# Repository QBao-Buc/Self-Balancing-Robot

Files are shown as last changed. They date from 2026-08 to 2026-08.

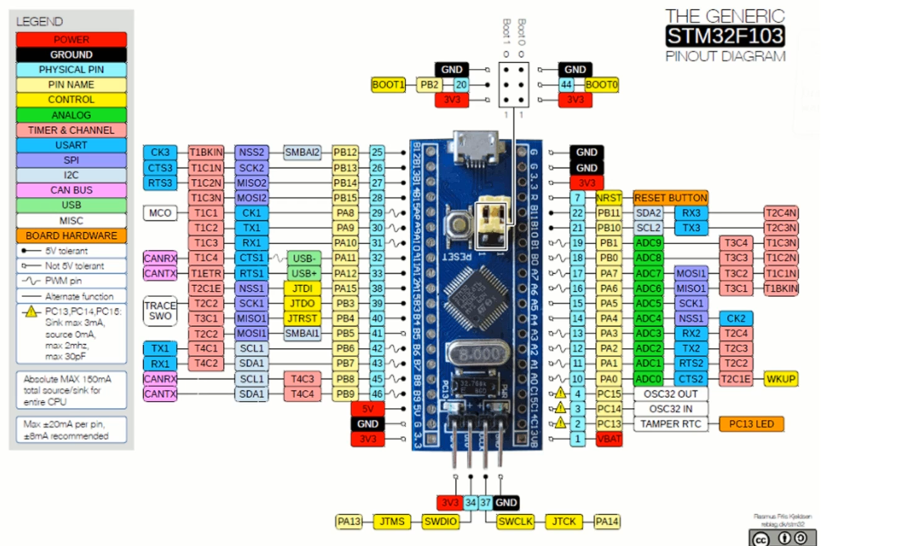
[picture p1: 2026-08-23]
docs/pinout/STM32.png

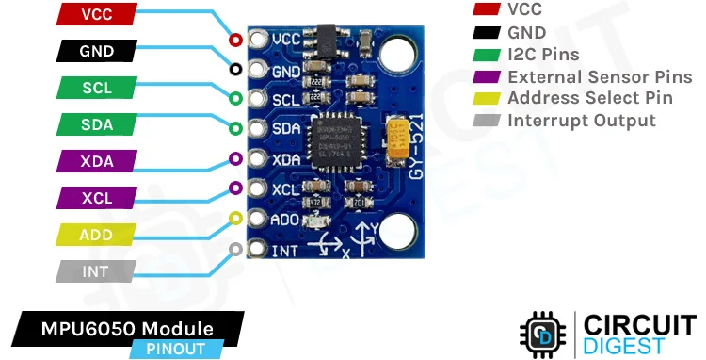
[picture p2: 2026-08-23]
docs/pinout/MPU6050-Module-Pinout.webp

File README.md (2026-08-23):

# Self-Balancing Robot (Dự án Nhúng Full-Stack)

Một dự án robot độc lập được thiết kế Full-Stack hoàn chỉnh: từ mạch cứng PCB tùy chỉnh, firmware nhúng C/C++, đến các thuật toán điều khiển PID trên vi điều khiển STM32.

---

## 📌 Tổng quan dự án

Dự án này tập trung vào việc thiết kế và chế tạo một robot 2 bánh tự cân bằng hoàn toàn từ con số 0. Hệ thống tích hợp toàn diện giữa thiết kế phần cứng, dung hợp cảm biến (sensor fusion), lý thuyết điều khiển rời rạc và lập trình hệ thống nhúng.

* **Vi điều khiển chính:** STM32F103C8T6 (Blue Pill)
* **Cảm biến:** MPU6050 (Góc nghiêng / Gia tốc 6-axis)
* **Mạch công suất:** TB6612FNG + Động cơ Encoder DC
* **Nguồn cấp:** Pin LiPo 3S (11.1V - 12.6V) qua mạch Hạ áp LM2596/Buck

---

## 🛠️ Kiến trúc Hệ thống & Đặc tính Kỹ thuật

* **Vi điều khiển:** Dòng STM32F103.
* **Phần cứng & PCB:** Thiết kế mạch nguyên lý & PCB 2 lớp tùy chỉnh, tích hợp khối cảm biến IMU MPU6050 và mạch điều khiển động cơ.
* **Firmware nhúng:** Lập trình C/C++ sử dụng thư viện STM32 HAL/Register, Ngắt bộ định thời (Timer Interrupts), và các ngoại vi I2C/PWM.
* **Chiến lược điều khiển:**
  * Dung hợp cảm biến thông qua Bộ lọc bù (Complementary Filter) / Bộ lọc Kalman để ước lượng góc nghiêng chính xác.
  * Thuật toán **PID 2 vòng kép (Cascade PID)** để cân bằng góc nghiêng, kiểm soát vận tốc và vị trí.
* **Cơ khí:** Thân vỏ khung xe in 3D tùy chỉnh được thiết kế trên SolidWorks.

---

## 📂 Cấu trúc Repository

```plaintext
Self-Balancing-Robot/
├── .gitignore
├── LICENSE
├── README.md
├── CHANGELOG.md
├── docs/                     # Tài liệu tham khảo, Datasheet & Handbook
│   ├── datasheets/           # Tập hợp Datasheet linh kiện (STM32, MPU6050, TB6612...)
│   ├── pinout/               # Sơ đồ gán chân & Pinout chi tiết
│   └── handbook/             # Nhật ký/Ghi chép quá trình phát triển & Debug
├── firmware/                 # Mã nguồn lập trình STM32 (CubeMX + Keil C)
│   ├── Core/
│   ├── Drivers/
│   ├── MDK-ARM/              # Project Keil C (.uvprojx)
│   ├── MyLib/                # Thư viện tự viết (robot_debug.c/h)
│   └── STM32F103_BalanceRobot.ioc
├── hardware/                 # Sơ đồ nguyên lý & PCB
│   ├── schematic/            # Bản vẽ nguyên lý (.PDF)
│   ├── wiring/               # Sơ đồ đấu nối dây (.PNG)
│   ├── pcb/                  # Layout PCB (.PDF)
│   └── BOM.md                # Danh mục linh kiện chi tiết
└── mechanical/               # Thiết kế cơ khí & Thân vỏ
    ├── cad/
    │   ├── circuit_parts/    # Mô hình 3D linh kiện điện tử
    │   │   ├── battery/      # Khối 3D Pin LiPo
    │   │   ├── buck/         # Khối 3D mạch hạ áp Buck
    │   │   ├── dong_co/      # Khối 3D động cơ Encoder
    │   │   ├── hc05/         # Khối 3D module Bluetooth HC-05
    │   │   ├── mpu/          # Khối 3D cảm biến MPU6050
    │   │   └── pcb/          # Khối 3D bo mạch PCB
    │   └── stl_print/        # File .STL phục vụ in 3D
    ├── drawings/             # Bản vẽ 3D tổng thể (.STEP) & bản vẽ 2D (.PDF)
    └── README.md             # Hướng dẫn in 3D & chế tạo
  
```
## 🚀 Tính năng chính của Robot
Giao tiếp & Debug: Gửi/nhận dữ liệu không dây qua Bluetooth HC-05, theo dõi thông số thực thời trên máy tính qua phần mềm Tera Term 5 (MyLib/robot_debug).

Cơ chế bảo vệ an toàn:
Dead Angle Protection: Tự động ngắt động cơ khi xe nghiêng quá góc cho phép (tránh trôi xe hoặc quá tải khi đổ).
Bảo vệ điện áp/Dòng: (Đang hoàn thiện)

Tính năng phụ trợ:
Điều khiển còi kèn (Buzzer) phát tín hiệu cảnh báo.
Hiệu ứng đèn LED trạng thái (nháy LED báo lỗi / chế độ hoạt động).
(Lưu ý: Các tính năng trên đang tiếp tục được tối ưu và hoàn thiện trong code).

## 📋 Danh mục chi tiết cần chuẩn bị (BOM)
Để xem danh sách đầy đủ tất cả linh kiện điện tử, động cơ, cảm biến và vật tư cơ khí cần chuẩn bị cho dự án:
👉 Mời bạn truy cập vào file: hardware/BOM.md

---

## 🛠️ Sơ đồ nguyên lý & Bảng chân đấu nối (Pinout)
### 1. Sơ đồ nguyên lý (Schematic)
(Phần này để trống - Cập nhật sơ đồ nguyên lý hoặc đường dẫn bản vẽ sau)

### 2. Sơ đồ đấu nối phần cứng
Chi tiết đấu nối giữa STM32, TB6612, Động cơ Encoder và Nguồn:

## 📖 Hướng dẫn lắp ráp & Vận hành
### 1. Phần cơ khí & Thân vỏ
In tất cả các file .STL nằm tại mechanical/cad/stl_print/ và xem bản vẽ lắp ráp tổng thể .STEP tại mechanical/drawings/.

### 2. Phần cứng & Nguồn
(Phần này để trống - Cập nhật hướng dẫn đấu nối chi tiết)

### 3. Nạp code Firmware
Mở project tại firmware/MDK-ARM/STM32F103_BalanceRobot.uvprojx bằng Keil uVision 5.

Build và nạp code xuống STM32 bằng mạch nạp ST-Link V2.

## 📄 Giấy phép (License)
Dự án được phân phối dưới giấy phép MIT License.

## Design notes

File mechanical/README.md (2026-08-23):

# 🛠️ Thiết kế Cơ khí & Thân vỏ (Mechanical)

Thư mục này chứa toàn bộ tài liệu thiết kế cơ khí, mô hình 3D linh kiện, file in 3D và bản vẽ lắp ráp cho robot tự cân bằng.

---

## 📂 Cấu trúc thư mục & Giải thích chức năng

```plaintext
mechanical/
├── README.md               # Hướng dẫn chi tiết phần cơ khí (File này)
├── cad/                    # Thư mục thiết kế mô hình 3D (CAD Models)
│   ├── circuit_parts/      # Mô hình 3D các linh kiện điện tử & bo mạch
│   │   ├── battery/        # Mô hình 3D Pin LiPo
│   │   ├── buck/           # Mô hình 3D mạch hạ áp Buck
│   │   ├── dong_co/        # Mô hình 3D động cơ DC Encoder
│   │   ├── hc05/           # Mô hình 3D Module Bluetooth HC-05
│   │   ├── mpu/            # Mô hình 3D Cảm biến MPU6050
│   │   └── pcb/            # Mô hình 3D Bo mạch PCB
│   └── stl_print/          # Các file định dạng .STL dùng để in 3D
└── drawings/               # Bản vẽ tổng thể & Kỹ thuật
    ├── *.STEP              # File lắp ráp 3D tổng thể (Assembly STEP)
    └── *.PDF               # Bản vẽ 2D / Sơ đồ chi tiết kích thước
```

## 📖 Hướng dẫn sử dụng từng phần

### 1. Thư mục cad/circuit_parts/ (Mô hình linh kiện điện tử)
Chức năng: Chứa mô hình 3D (STEP/SolidWorks) của từng linh kiện điện tử thực tế.

Cách dùng: Sử dụng khi bạn muốn tự thiết kế lại khung xe/PCB bằng các phần mềm CAD (SolidWorks, Fusion 360, Inventor). Hãy Import các file này vào phần mềm thiết kế để lấy chính xác kích thước và vị trí bắt ốc.

### 2. Thư mục cad/stl_print/ (File in 3D)
Chức năng: Chứa các file định dạng .STL của thân vỏ, gá động cơ, khay pin đã được tối ưu cho máy in 3D.

Cách dùng:

Mở phần mềm Cắt lát (Slicer) như Cura, PrusaSlicer, hoặc Bambu Studio.

Import tất cả file .STL trong thư mục này.

Tiến hành Cắt lát (Slice) và xuất file .gcode ra thẻ nhớ để đưa vào máy in 3D.

Khuyến nghị thông số in: Infill 20% - 30% (dạng Gyroid/Grid), độ dày thành (Wall thickness) >= 1.2mm, vật liệu in PLA hoặc PETG.

### 3. Thư mục drawings/ (Bản vẽ tổng thể)
Chức năng: Chứa bản vẽ phối cảnh 3D tổng thể (.STEP) và bản vẽ kỹ thuật 2D (.PDF).

Cách dùng:

File .STEP: Mở bằng phần mềm CAD để xem tổng thể robot sau khi lắp ráp đầy đủ khung, động cơ, mạch và pin.

File .PDF: Xem trực tiếp để nắm kích thước tổng thể robot và vị trí lắp ghép chuẩn.

## 👉 Để quay lại hướng dẫn chung của toàn bộ dự án, truy cập Trang README chính.

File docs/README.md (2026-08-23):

# 📚 Tài liệu tham khảo & Nhật ký phát triển (Docs)

Thư mục này chứa toàn bộ các tài liệu kỹ thuật, datasheet linh kiện, bản đồ gán chân (Pinout Mapping) và tài liệu nhật ký ghi chép quá trình nghiên cứu, chế tạo robot tự cân bằng.

---

## 📂 Cấu trúc lưu trữ

```plaintext
docs/
├── README.md               # Trang hướng dẫn & Tổng quan thư mục tài liệu
├── datasheets/             # Tập hợp Datasheet PDF của các linh kiện
├── pinout/                 # Sơ đồ kết nối chân & Bảng tra cứu Pinout chi tiết
└── handbook/               # Nhật ký ghi chép, tài liệu tính toán & Debug
```

---

## 📖 Danh mục tài liệu chi tiết

### 1. 📄 Datasheets (`docs/datasheets/`)
Tài liệu kỹ thuật gốc từ nhà sản xuất phục vụ tra cứu thông số điện áp, dòng điện, thanh ghi (registers) và các chuẩn giao tiếp:
* **STM32F103C8T6:** Datasheet vi điều khiển ARM Cortex-M3 & Reference Manual (`RM0008`).
* **MPU6050:** Product Specification & Register Map (Bộ lọc dung hợp cảm biến IMU 6-axis).
* **TB6612FNG:** Datasheet mạch cầu H điều khiển động cơ DC.
* **HC-05:** Tài liệu cấu hình Bluetooth Module & Tập lệnh AT Command.
* **LM2596 / Buck Converter:** Datasheet mạch nguồn hạ áp.

---

### 2. 📌 Pinout & Sơ đồ đấu nối (`docs/pinout/`)
* **Sơ đồ gán chân tổng thể:** Bảng tra cứu chân kết nối giữa STM32F103C8T6 với các ngoại vi (I2C MPU6050, Timer Encoder, PWM TB6612, UART Bluetooth).
* **Sơ đồ mạch nguyên lý & Wiring:** Bản vẽ kết nối dây thực tế giúp người dùng có thể lắp ráp nhanh chóng.

---

### 3. 📝 Handbook & Nhật ký dự án (`docs/handbook/`)
Tài liệu hướng dẫn chuyên sâu từ con số 0:
* **Lý thuyết & Thuật toán:** Giải thuật lọc bù (Complementary Filter), Kalman Filter và thuật toán điều khiển PID 2 vòng kép (Cascade PID).
* **Kinh nghiệm cân chỉnh (PID Tuning):** Quy trình thực tế để chỉnh các thông số $K_p, K_i, K_d$.
* **Xử lý sự cố (Troubleshooting):** Tổng hợp các vấn đề thường gặp (nhiễu IMU, trôi góc 0, sụt áp do động cơ, nhiễu nguồn...) và cách khắc phục.

---

👉 *Để xem hướng dẫn nạp code và chạy dự án, vui lòng quay lại [Trang README chính](../README.md).*

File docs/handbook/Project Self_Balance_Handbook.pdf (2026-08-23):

Nguyễn Quốc Bảo
Sinh viên Công nghệ kĩ thuật, ngành cơ điện tử, khóa K24

Điều khiển động cơ bằng PWM
Nhiệm vụ số 1: _Điều khiển được động cơ bằng PWM

_Sử dụng được encoder + Điều khiển tốc độ động cơ + số chân cắm vào phải tương ứng với mạch
Nhiệm vụ nhỏ:
Xác định toàn bộ chân động cơ ở trong ảnh -> viết lại dưới dạng mạch breadboard ở fritzing

#MINI TASK: Điều khiển được tốc độ của động cơ DC thông qua TB6612 bằng PWM + sử dụng các cổng trùng với sơ đồ minh họa , (tôi điều khiển động cơ với tốc độ từ 0% -> 100% sau đó 100%->0%) _motor trái

Màu dây / Tên cổng | Chức năng | Nối vào
⚪White (1) | Cực 1 Motor | BO1 (TB6612)
Blue (2) | Encoder VCC | 3.3V (STM32)
Green (3) | Encoder Channel B | B10 STM32 (TIMx_CH2 hoặc GPIO)
Yellow (4) | Encoder Channel A | B11 STM32 (TIMx_CH1 hoặc GPIO)
⚫Black (5) | Encoder GND | GND
Red (6) | Cực 2 Motor | BO2 (TB6612)

#NOTE: khi đấu mạch, phải đảm bảo

_cực âm của Pin, GND của STM32, GND của TB6612 phải được nối đến GND chung, nếu không nó sẽ không chạy.

_Chân STBY (standby) ở TB6612: Công tắc bật/tắt driver -> HIGH -> Driver hoạt động -> động cơ chạy
_Chân BO1và BO2: dung để đấu vào 2 cực của động cơ để điều khiển

_motor phải
Màu dây / Tên cổng | Chức năng | Nối vào
⚪White (1) | Cực 1 Motor | AO1 (TB6612)
Blue (2) | Encoder VCC | 3.3V (STM32)
Green (3) | Encoder Channel B | B08 STM32 (TIMx_CH2 hoặc GPIO)
Yellow (4) | Encoder Channel A | B09 STM32 (TIMx_CH1 hoặc GPIO)
⚫Black (5) | Encoder GND | GND
Red | (6) | Cực 2 Motor | AO2 (TB6612) _TB6612:
Cổng TB6612 | Nối đến | Cổng TB6612 | Nối đến
VM | 12V | PWMA | A0
VCC | 3.3V | AI1 | A2
GND | GND | AI2 | A3
A01 | WHITE (động cơ R) | STBY | A4 (HIGH/LOW)
A02 | RED( động cơ R) | BI1 | A5
B02 | WHITE (động cơ L) | BI2 | A6
B01 | RED (động cơ L) | PWMB | A1
GND | GND (STM32) | GND

Cấu hình CubeMX:

### 1. RCC

HSE = Crystal/Ceramic Resonator

### 2. SYS

Debug = Serial Wire

### 3. Clock Configuration

Mục | Giá trị
HSE | 8 MHz
PLL Source HSE
PLL Mul | ×9
SYSCLK | 72 MHz
AHB | /1
APB1 | /2
APB2 | /1
ADC | /6

### 4. TIM2 (PWM)

Enable:
TIM2
Chọn
Channel | Mode
CH1 | PWM Generation CH1
CH2 | PWM Generation CH2
Parameter Settings
Thông số | Giá trị
Prescaler | 0

Thông số | Giá trị
Counter Period (ARR) | 3599
Counter Mode | Up
Clock Division | DIV1
Auto Reload Preload | Enable
Lúc này

### 72 MHz

↓
ARR = 3599
↓
PWM = 20 kHz
Đây là tần số rất phổ biến cho điều khiển động cơ DC vì nằm ngoài dải nghe của tai người. 5. GPIO
Pin | Mode | Label
PA2 | GPIO_Output | AIN1
PA3 | GPIO_Output | AIN2
PA4 | GPIO_Output | STBY
PA5 | GPIO_Output | BIN1
PA6 | GPIO_Output | BIN2

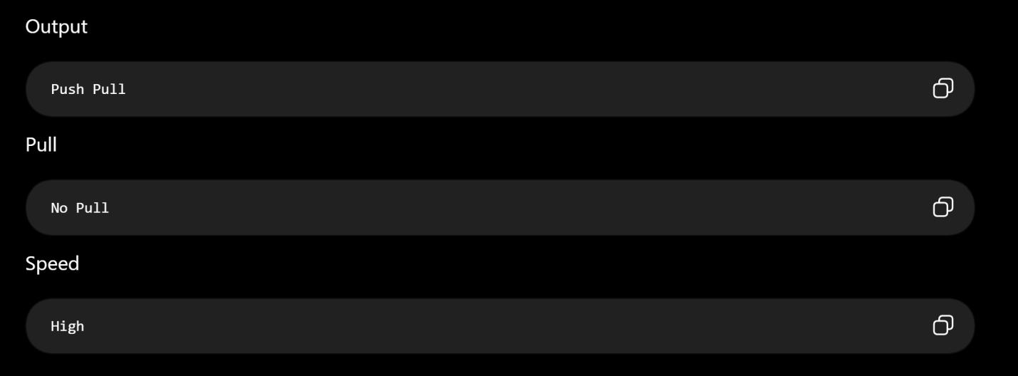
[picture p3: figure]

### 6. PWM Pins

CubeMX sẽ tự gán
Pin | Chức năng
PA0 TIM2_CH1
PA1 TIM2_CH2

### 7. Encoder

Tạm thời
Pin | Mode
PB10 GPIO_Input
PB11 GPIO_Input

### 8. NVIC

Hiện tại Không cần bật Interrupt

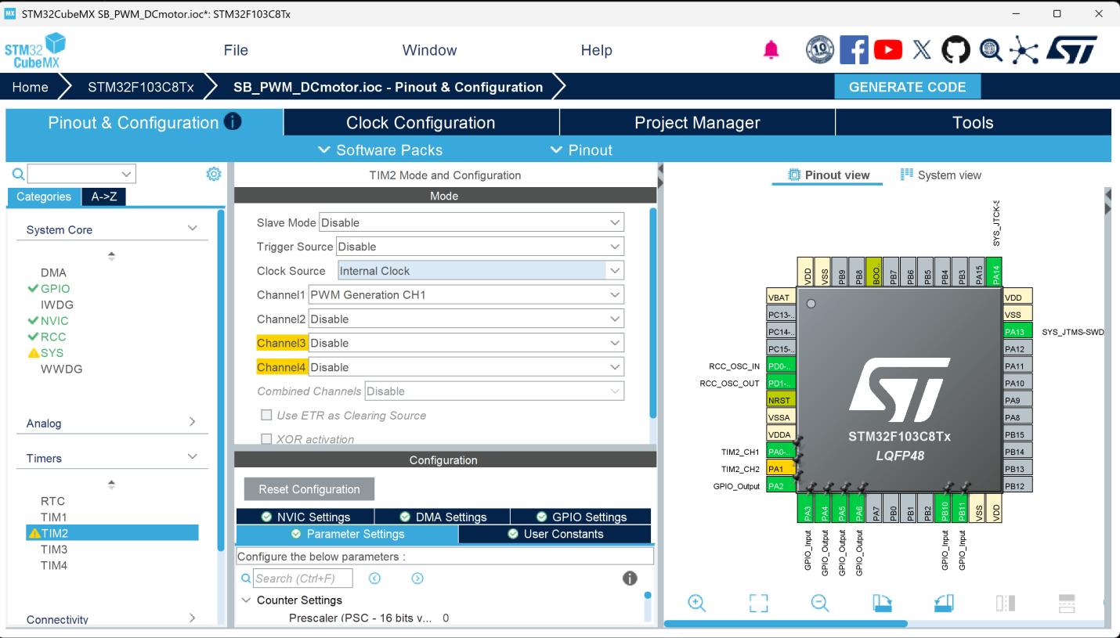
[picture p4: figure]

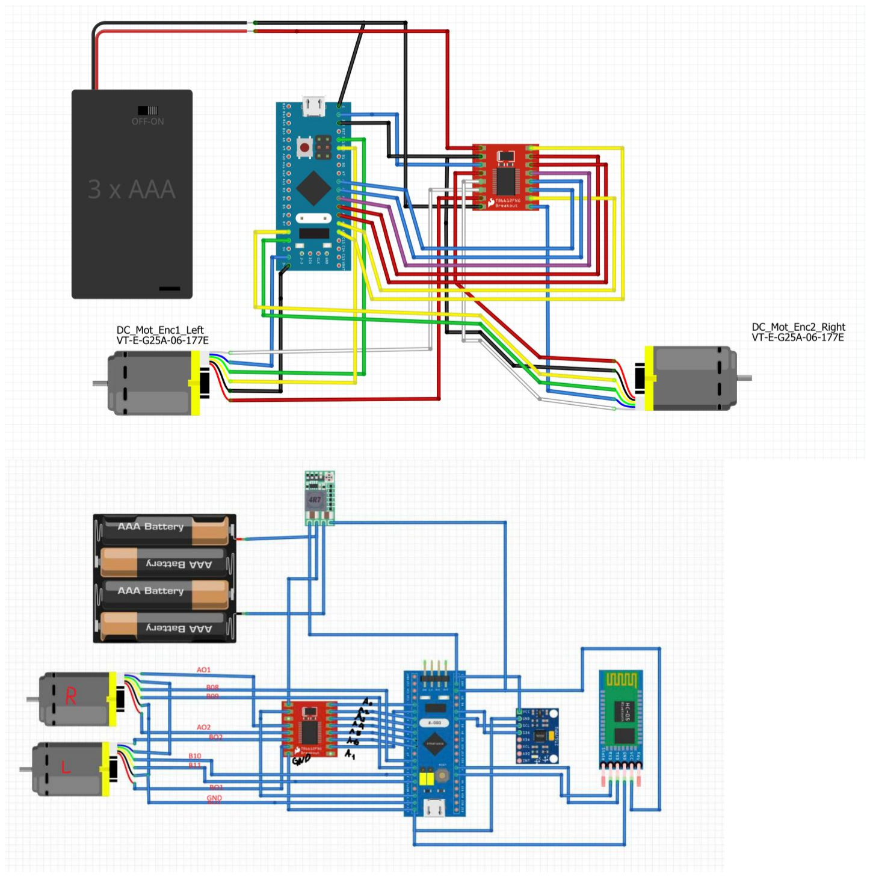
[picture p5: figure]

#note: cái hình này chưa hẳn đã đúng, nên kiểm tra lại tính chính xác, bởi vì gần đây đã có sự thay đổi về mặt phần cứng

### 1. STM32 ↔ TB6612

STM32 Chế độ trong CubeMX TB6612 Chức năng
PA0 | TIM2_CH1 (PWM) | PWMA | Điều khiển tốc độ động cơ phải
PA1 | TIM2_CH2 (PWM) | PWMB | Điều khiển tốc độ động cơ trái
PA2 | GPIO Output | AIN1 | Chiều quay động cơ phải
PA3 | GPIO Output | AIN2 | Chiều quay động cơ phải
PA4 | GPIO Output | STBY | Enable TB6612
PA5 | GPIO Output | BIN1 | Chiều quay động cơ trái
PA6 | GPIO Output | BIN2 | Chiều quay động cơ trái
3.3V | Power | VCC | Nguồn logic TB6612
GND | GND | GND | Mass chung

### 2. TB6612 ↔ Động cơ

Động cơ phải
TB6612 | Động cơ
AO1 | White
AO2 | Red
Động cơ trái
TB6612 | Động cơ
BO1 | Red
BO2 | White

### 3. Encoder động cơ trái

Dây encoder | STM32 | Chức năng
Black | 3.3V | VCC
Blue | GND | GND
Yellow | PB11 | Channel A
Green | PB10 | Channel B

### 4. Nguồn

Nguồn | TB6612
+12V (hoặc nguồn động cơ của bạn) | VM
3.3V STM32 | VCC
GND nguồn | GND
GND STM32 | GND
Lưu ý: GND của STM32, TB6612 và nguồn động cơ phải nối chung. 5. Các chân đang được chương trình sử dụng

STM32 Chức năng
PA0 | PWM Motor Right
PA1 | PWM Motor Left
PA2 | AIN1
PA3 | AIN2

STM32 Chức năng
PA4 | STBY
PA5 | BIN1
PA6 | BIN2
PB10 | Encoder B (chưa sử dụng trong code)
PB11 | Encoder A (chưa sử dụng trong code)

### 6. Trạng thái các chân trong chương trình

Khi quay thuận
Chân | Mức
STBY | HIGH
AIN1 | HIGH
AIN2 | LOW
BIN1 | HIGH
BIN2 | LOW
PWMA | PWM 0 → 100%
PWMB | PWM 0 → 100%

Khi quay ngược
Chân | Mức
STBY | HIGH

Chân | Mức
AIN1 | LOW
AIN2 | HIGH
BIN1 | LOW
BIN2 | HIGH
PWMA | PWM 0 → 100%
PWMB | PWM 0 → 100%

#MiniTask 2: Việc của bạn là sử dụng được Encoder của động cơ, hiển thị các thông số vị trí của bánh 1 và bánh 2, yêu cầu đấu nối giống với những gì đã thiết lập

<đã xong> (file

#MiniTask3: Việc của bạn là thử điều khiển PID nó, thử tác động một lực quay nhất định rồi yêu cầu nó quay trở về vị trí cũ. <đã xong>

/* USER CODE BEGIN Header */
/**
******************************************************************************
* @file | : main.c
* @brief | : Main program body
****************************************************************************** * @attention
*

* Copyright (c) 2026 STMicroelectronics. * All rights reserved. *

* This software is licensed under terms that can be found in the LICENSE file * in the root directory of this software component. * If no LICENSE file comes with this software, it is provided AS-IS. *

****************************************************************************** */
/* USER CODE END Header */
/* Includes ------------------------------------------------------------------*/ #include "main.h"

/* Private includes ----------------------------------------------------------*/ /* USER CODE BEGIN Includes */

/* USER CODE END Includes */

/* Private typedef -----------------------------------------------------------*/ /* USER CODE BEGIN PTD */

/* USER CODE END PTD */

/* Private define ------------------------------------------------------------*/

/* USER CODE BEGIN PD */

/* USER CODE END PD */

/* Private macro -------------------------------------------------------------*/ /* USER CODE BEGIN PM */

/* USER CODE END PM */

/* Private variables ---------------------------------------------------------*/ TIM_HandleTypeDef htim2;
TIM_HandleTypeDef htim3;

/* USER CODE BEGIN PV */
int pwm = 0;
volatile int32_t encoder_position = 0; volatile int16_t cnt = 0;
int16_t encoder_last = 0;
int32_t target_position = 0;

/* PID */
float Kp = 0.1f;

float Ki = 0.01f;
float Kd = 0.5f;

float integral = 0.0f;
float previous_error = 0.0f; float last_error = 0;
float derivative = 0.0f;

float error = 0;

/* USER CODE END PV */

/* Private function prototypes -----------------------------------------------*/ void SystemClock_Config(void);
static void MX_GPIO_Init(void);
static void MX_TIM2_Init(void);
static void MX_TIM3_Init(void);
/* USER CODE BEGIN PFP */
void HAL_TIM_MspPostInit(TIM_HandleTypeDef *htim); void Motor_SetPWM(int pwm);

void Encoder_Update(void);

/* USER CODE END PFP */

/* Private user code ---------------------------------------------------------*/ /* USER CODE BEGIN 0 */

/* USER CODE END 0 */

/**
* @brief The application entry point. * @retval int

*/
int main(void)
{

/* USER CODE BEGIN 1 */

/* USER CODE END 1 */

/* MCU Configuration--------------------------------------------------------*/

/* Reset of all peripherals, Initializes the Flash interface and the Systick. */ HAL_Init();

/* USER CODE BEGIN Init */

/* USER CODE END Init */

/* Configure the system clock */ SystemClock_Config();

/* USER CODE BEGIN SysInit */

/* USER CODE END SysInit */

/* Initialize all configured peripherals */ MX_GPIO_Init();
MX_TIM2_Init();
MX_TIM3_Init();
/* USER CODE BEGIN 2 */
// Khoi dong cc knh xung PWM trn TIMER 2 HAL_TIM_PWM_Start(&htim2, TIM_CHANNEL_1); HAL_TIM_PWM_Start(&htim2, TIM_CHANNEL_2);
// Bat chn STBY de kch hoat IC driver TB6612 (PA4) HAL_GPIO_WritePin(GPIOA, GPIO_PIN_4, GPIO_PIN_SET);

HAL_TIM_Encoder_Start(&htim3, TIM_CHANNEL_ALL); encoder_last = (int16_t)__HAL_TIM_GET_COUNTER(&htim3); Encoder_Update();
target_position = encoder_position;
Encoder_Update();

/* USER CODE END 2 */

/* Infinite loop */
/* USER CODE BEGIN WHILE */ volatile int32_t temp = 0;

while (1)
{
/* USER CODE END WHILE */

/* USER CODE BEGIN 3 */
Encoder_Update();

cnt = (int16_t)__HAL_TIM_GET_COUNTER(&htim3); error = target_position - encoder_position;

// Khâu Tích phân (I)
integral += error;

// integral Windup
if(integral > 5000) integral = 5000; if(integral < -5000) integral = -5000;

// Khâu Vi phân (D)
derivative = error - last_error;

// Tính toán đầu ra PID
pwm = (int)(Kp * error + Ki * integral + Kd * derivative);

// CẬP NHẬT SAI SỐ CŨ CHO CHU KỲ SAU (BẮT BUỘC) last_error = error;

// Vùng chết (Deadband)
if(error > -3 && error < 3) {
pwm = 0;
}

// Giới hạn điện áp PWM đầu ra chống quá tải hệ thống if(pwm > 1200) pwm = 1200;

if(pwm < -1200) pwm = -1200;

Motor_SetPWM(pwm);

HAL_Delay(5);
}
/* USER CODE END 3 */
}

/**
* @brief System Clock Configuration * @retval None
*/
void SystemClock_Config(void)
{
RCC_OscInitTypeDef RCC_OscInitStruct = {0};
RCC_ClkInitTypeDef RCC_ClkInitStruct = {0};

/** Initializes the RCC Oscillators according to the specified parameters * in the RCC_OscInitTypeDef structure. */

RCC_OscInitStruct.OscillatorType = RCC_OSCILLATORTYPE_HSE; RCC_OscInitStruct.HSEState = RCC_HSE_ON; RCC_OscInitStruct.HSEPredivValue = RCC_HSE_PREDIV_DIV1;

RCC_OscInitStruct.HSIState = RCC_HSI_ON; RCC_OscInitStruct.PLL.PLLState = RCC_PLL_ON; RCC_OscInitStruct.PLL.PLLSource = RCC_PLLSOURCE_HSE; RCC_OscInitStruct.PLL.PLLMUL = RCC_PLL_MUL9;
if (HAL_RCC_OscConfig(&RCC_OscInitStruct) != HAL_OK) {
Error_Handler();
}

/** Initializes the CPU, AHB and APB buses clocks
*/
RCC_ClkInitStruct.ClockType = RCC_CLOCKTYPE_HCLK|RCC_CLOCKTYPE_SYSCLK |RCC_CLOCKTYPE_PCLK1|RCC_CLOCKTYPE_PCLK2; RCC_ClkInitStruct.SYSCLKSource = RCC_SYSCLKSOURCE_PLLCLK; RCC_ClkInitStruct.AHBCLKDivider = RCC_SYSCLK_DIV1; RCC_ClkInitStruct.APB1CLKDivider = RCC_HCLK_DIV2; RCC_ClkInitStruct.APB2CLKDivider = RCC_HCLK_DIV1;

if (HAL_RCC_ClockConfig(&RCC_ClkInitStruct, FLASH_LATENCY_2) != HAL_OK) {
Error_Handler();
}
}

/**
* @brief TIM2 Initialization Function * @param None
* @retval None
*/
static void MX_TIM2_Init(void)
{

/* USER CODE BEGIN TIM2_Init 0 */

/* USER CODE END TIM2_Init 0 */

TIM_ClockConfigTypeDef sClockSourceConfig = {0}; TIM_MasterConfigTypeDef sMasterConfig = {0}; TIM_OC_InitTypeDef sConfigOC = {0};

/* USER CODE BEGIN TIM2_Init 1 */

/* USER CODE END TIM2_Init 1 */
htim2.Instance = TIM2;
htim2.Init.Prescaler = 0;
htim2.Init.CounterMode = TIM_COUNTERMODE_UP; htim2.Init.Period = 3599;
htim2.Init.ClockDivision = TIM_CLOCKDIVISION_DIV1;

htim2.Init.AutoReloadPreload = TIM_AUTORELOAD_PRELOAD_ENABLE; if (HAL_TIM_Base_Init(&htim2) != HAL_OK)
{
Error_Handler();
}
sClockSourceConfig.ClockSource = TIM_CLOCKSOURCE_INTERNAL;
if (HAL_TIM_ConfigClockSource(&htim2, &sClockSourceConfig) != HAL_OK) {
Error_Handler();
}
if (HAL_TIM_PWM_Init(&htim2) != HAL_OK) {
Error_Handler();
}
sMasterConfig.MasterOutputTrigger = TIM_TRGO_RESET; sMasterConfig.MasterSlaveMode = TIM_MASTERSLAVEMODE_DISABLE; if (HAL_TIMEx_MasterConfigSynchronization(&htim2, &sMasterConfig) != HAL_OK)

{
Error_Handler();
}
sConfigOC.OCMode = TIM_OCMODE_PWM1; sConfigOC.Pulse = 0;
sConfigOC.OCPolarity = TIM_OCPOLARITY_HIGH; sConfigOC.OCFastMode = TIM_OCFAST_DISABLE;

if (HAL_TIM_PWM_ConfigChannel(&htim2, &sConfigOC, TIM_CHANNEL_1) != HAL_OK)

{
Error_Handler();
}
if (HAL_TIM_PWM_ConfigChannel(&htim2, &sConfigOC, TIM_CHANNEL_2) != HAL_OK)

{
Error_Handler();
}
/* USER CODE BEGIN TIM2_Init 2 */

/* USER CODE END TIM2_Init 2 */ HAL_TIM_MspPostInit(&htim2);

}

/**
* @brief TIM3 Initialization Function * @param None
* @retval None
*/
static void MX_TIM3_Init(void) {

/* USER CODE BEGIN TIM3_Init 0 */

/* USER CODE END TIM3_Init 0 */

TIM_Encoder_InitTypeDef sConfig = {0}; TIM_MasterConfigTypeDef sMasterConfig = {0};

/* USER CODE BEGIN TIM3_Init 1 */

/* USER CODE END TIM3_Init 1 */
htim3.Instance = TIM3;
htim3.Init.Prescaler = 0;
htim3.Init.CounterMode = TIM_COUNTERMODE_UP; htim3.Init.Period = 65535;
htim3.Init.ClockDivision = TIM_CLOCKDIVISION_DIV1; htim3.Init.AutoReloadPreload = TIM_AUTORELOAD_PRELOAD_DISABLE; sConfig.EncoderMode = TIM_ENCODERMODE_TI12; sConfig.IC1Polarity = TIM_ICPOLARITY_RISING;
sConfig.IC1Selection = TIM_ICSELECTION_DIRECTTI; sConfig.IC1Prescaler = TIM_ICPSC_DIV1; sConfig.IC1Filter = 10;
sConfig.IC2Polarity = TIM_ICPOLARITY_RISING; sConfig.IC2Selection = TIM_ICSELECTION_DIRECTTI; sConfig.IC2Prescaler = TIM_ICPSC_DIV1;

sConfig.IC2Filter = 10;
if (HAL_TIM_Encoder_Init(&htim3, &sConfig) != HAL_OK) {
Error_Handler();
}
sMasterConfig.MasterOutputTrigger = TIM_TRGO_RESET; sMasterConfig.MasterSlaveMode = TIM_MASTERSLAVEMODE_DISABLE; if (HAL_TIMEx_MasterConfigSynchronization(&htim3, &sMasterConfig) != HAL_OK)

{
Error_Handler();
}
/* USER CODE BEGIN TIM3_Init 2 */

/* USER CODE END TIM3_Init 2 */

}

/**
* @brief GPIO Initialization Function * @param None
* @retval None
*/
static void MX_GPIO_Init(void) {

GPIO_InitTypeDef GPIO_InitStruct = {0}; /* USER CODE BEGIN MX_GPIO_Init_1 */

/* USER CODE END MX_GPIO_Init_1 */

/* GPIO Ports Clock Enable */ __HAL_RCC_GPIOD_CLK_ENABLE(); __HAL_RCC_GPIOA_CLK_ENABLE(); __HAL_RCC_GPIOB_CLK_ENABLE();

/*Configure GPIO pin Output Level */
HAL_GPIO_WritePin(GPIOA, GPIO_PIN_2|GPIO_PIN_3|GPIO_PIN_4|GPIO_PIN_5 |GPIO_PIN_6, GPIO_PIN_RESET);

/*Configure GPIO pins : PA2 PA3 PA4 PA5
PA6 */
GPIO_InitStruct.Pin = GPIO_PIN_2|GPIO_PIN_3|GPIO_PIN_4|GPIO_PIN_5 |GPIO_PIN_6;
GPIO_InitStruct.Mode = GPIO_MODE_OUTPUT_PP; GPIO_InitStruct.Pull = GPIO_NOPULL;
GPIO_InitStruct.Speed = GPIO_SPEED_FREQ_LOW; HAL_GPIO_Init(GPIOA, &GPIO_InitStruct);

/* USER CODE BEGIN MX_GPIO_Init_2 */

/* USER CODE END MX_GPIO_Init_2 */ }

/* USER CODE BEGIN 4 */

// Hm x? l ng?t ngoi d? d?m xung Encoder t? chn PB10 v PB11

void Motor_SetPWM(int pwm)
{
// Giới hạn giá trị PWM đầu ra theo cấu hình Timer (Period = 3599) if(pwm > 3599) pwm = 3599;
if(pwm < -3599) pwm = -3599;

if(pwm <= 0) // Quay thuận khi pwm dương hoặc bằng 0 {
// QUAY THUAN: IN1 = 1, IN2 = 0 HAL_GPIO_WritePin(GPIOA, GPIO_PIN_5, GPIO_PIN_SET); HAL_GPIO_WritePin(GPIOA, GPIO_PIN_6, GPIO_PIN_RESET);

// Nạp giá trị PWM dương trực tiếp __HAL_TIM_SET_COMPARE(&htim2, TIM_CHANNEL_2, pwm); }
else // Quay nghịch khi pwm < 0

{
// QUAY NGHICH: IN1 = 0, IN2 = 1 HAL_GPIO_WritePin(GPIOA, GPIO_PIN_5, GPIO_PIN_RESET); HAL_GPIO_WritePin(GPIOA, GPIO_PIN_6, GPIO_PIN_SET);

// ĐỔI DẤU SỐ ÂM THÀNH SỐ DƯƠNG (Thêm dấu trừ) __HAL_TIM_SET_COMPARE(&htim2, TIM_CHANNEL_2, -pwm);

}
}

void Encoder_Update(void)
{
int16_t now;
int16_t delta;

now = (int16_t)__HAL_TIM_GET_COUNTER(&htim3);

delta = now - encoder_last;

encoder_last = now;

encoder_position += delta; }
/* USER CODE END 4 */

/**
* @brief This function is executed in case of error occurrence. * @retval None

*/
void Error_Handler(void)
{
/* USER CODE BEGIN Error_Handler_Debug */
/* User can add his own implementation to report the HAL error return state */ __disable_irq();
while (1)
{
}
/* USER CODE END Error_Handler_Debug */ }
#ifdef USE_FULL_ASSERT

/**
* @brief Reports the name of the source file and the source line number * where the assert_param error has occurred. * @param file: pointer to the source file name

* @param line: assert_param error line source number
* @retval None
*/
void assert_failed(uint8_t *file, uint32_t line)

{
/* USER CODE BEGIN 6 */
/* User can add his own implementation to report the file name and line number, ex: printf("Wrong parameters value: file %s on line %d\r\n", file, line) */

/* USER CODE END 6 */
}
#endif /* USE_FULL_ASSERT */

#NOTE: đổi chân encoder motor trái thành PB4 PB5

#MiniTask4: Tìm ra bài toán động học và làm sao cho nó đứng được. #MiniTask5: Tunning bằng module blue tooth, học cách sử dụng và Tunning

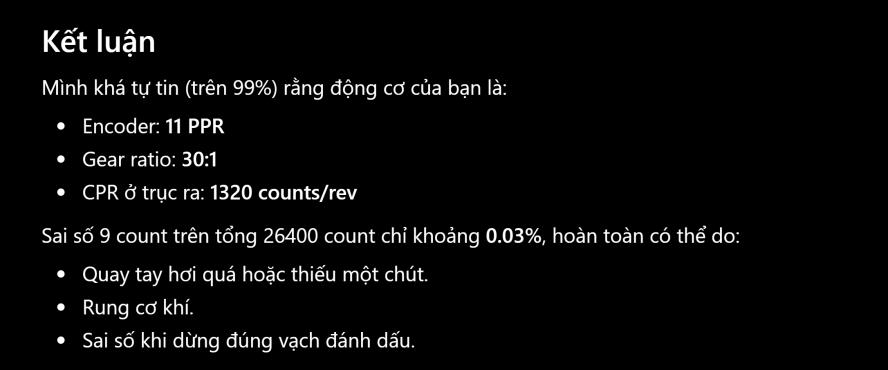
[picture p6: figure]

#MINI TASK 3.2: encoder speed: sử dụng encoder để tính tốc độ RPM để phục vụ cho bài toán động học giữa MPU và Động cơ. Module 1: Encoder Speed

Mục tiêu
Mỗi 10 ms tính được:

Position (count)
↓

Delta Count

↓

RPM

↓

Filtered RPM

Bước 1. Cấu hình CubeMX
TIM3
Giữ nguyên như hiện tại
Mode:
Encoder Mode

Prescaler = 0

Period = 65535

Encoder Mode = TI12

IC1 Filter = 10

IC2 Filter = 10

TIM4
Tạo timer định kỳ. Ví dụ Clock:

### 72 MHz

Ta muốn

### 10 ms => 100 Hz

Chọn
PSC = 7199

ARR = 99
Vì

### 72 MHz

↓

72000000/(7199+1) =

10000 Hz

↓

10000/(99+1) =

100 Hz =

### 10 ms

Sau đó
Enable Update Interrupt

Bước 2. Tạo biến
Ngay đầu main.c
typedef struct
{
int32_t position;
int32_t last_position;
int32_t delta;

float rpm;
float rpm_filter;

}Encoder_t;

Encoder_t encoder;

Bước 3. Thêm

#define ENCODER_CPR | 1320.0f

#define SAMPLE_TIME | 0.01f

#define RPM_FACTOR (60.0f/(ENCODER_CPR*SAMPLE_TIME)) Compiler sẽ tính sẵn

RPM_FACTOR =

4.54545

Bước 4. Khởi động

HAL_TIM_Encoder_Start(&htim3,TIM_CHANNEL_ALL);

HAL_TIM_Base_Start_IT(&htim4);

Bước 5. Viết hàm

void Encoder_Update(void)
{
encoder.position = (int16_t)__HAL_TIM_GET_COUNTER(&htim3);

encoder.delta =
encoder.position - encoder.last_position;

encoder.last_position =
encoder.position;

encoder.rpm =
encoder.delta * RPM_FACTOR;

encoder.rpm_filter =
0.8f*encoder.rpm_filter+
0.2f*encoder.rpm;
}
#Side Quest: Hiện tại việc Debug PID rất phiền, nên chúng ta chuyển sang sử dụng UART để debug -> học sử dụng HC-05 bluetooth trước

HC-05
STATE
RXD | PA9
TXD | PA10
GND | GND
VCC | 5V
EN
PA9 PA10

Bước 1: Kết nối phần cứng
Nếu dùng USART1 của Blue Pill: HC-05 STM32F103
VCC 5V
GND GND
TXD PA10 (USART1_RX)
RXD PA9 (USART1_TX)
Lưu ý
TX luôn nối RX
RX luôn nối TX
STM32 PA9 ----------> RX HC05

STM32 PA10 <---------- TX HC05

Bước 2: CubeMX

Mở CubeMX. USART1

Chọn
Mode

Asynchronous

Baudrate
9600

Word Length

### 8 Bits

Parity
None

Stop Bits
1

Hardware Flow Control
None

Mode
TX and RX

DMA
Disable
Interrupt
Disable
Hiện tại chúng ta chỉ truyền dữ liệu nên chưa cần ngắt. Bước 3: Clock

Để USART ổn định:
SYSCLK = 72 MHz
Nếu trước đó Motor và Encoder hoạt động bình thường thì giữ nguyên. Bước 4: Kiểm tra HC-05

Cấp nguồn. Quan sát LED. Trường hợp 1

LED nhấp nhanh
- • • • • • => Chưa kết nối Bluetooth. Đây là trạng thái bình thường. Trường hợp 2

LED nhấp chậm
- • • => Đã kết nối điện thoại.

Bước 5: Ghép nối điện thoại Bật Bluetooth. Tìm

HC-05
Nếu hỏi mật khẩu
1234
hoặc
0000
Theo datasheet, mã PIN mặc định có thể là 0000 trong chế độ hoạt động và 1234 sau khi khôi phục mặc định bằng AT+ORGL, tùy firmware của module. Bước 6

Cài ứng dụng
Serial Bluetooth Terminal
(Đây là ứng dụng mình thường dùng để debug UART qua HC-05.)

Bước 7
Sau khi Pair thành công
Kết nối tới HC-05. Nếu LED chuyển sang nhấp chậm

=> Thành công. Bước 8

Chưa cần viết code.

Mình muốn kiểm tra phần cứng trước. Bạn hãy gửi cho mình:

1. Ảnh module HC-05 của bạn (hai mặt nếu được) để xem đây là bản ZS-040, FC-114 hay loại khác. 2. File .ioc hiện tại của dự án STM32 (hoặc ảnh cấu hình CubeMX phần

USART1). Sau khi mình kiểm tra cấu hình, chúng ta sẽ sang Bài 2, chỉ với khoảng 10 dòng

code để STM32 gửi:
Hello STM32
Nếu điện thoại nhận được dòng này, tức là toàn bộ đường truyền STM32 → UART → HC-05 → Bluetooth đã hoạt động chính xác. Sau đó chúng ta mới bắt đầu xây

dựng thư viện Bluetooth.

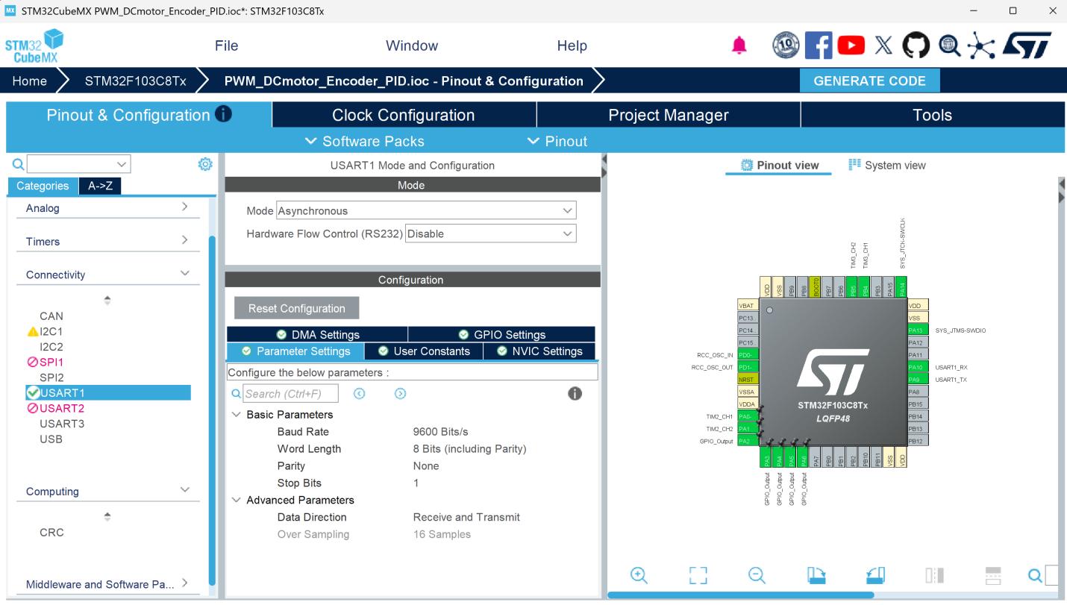
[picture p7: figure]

Kiểm tra phần cứng
Hãy nối đúng như sau:
HC-05 STM32

HC-05 STM32
VCC 5V
GND GND
TXD PA10 (RX1)
RXD PA9 (TX1)
⚠ Lưu ý quan trọng: • TX của HC-05 → RX của STM32
- RX của HC-05 ← TX của STM32

void HAL_UART_RxCpltCallback(UART_HandleTypeDef *huart) {
if(huart->Instance == USART1)
{
HAL_UART_Transmit(&huart1,&rxChar,1,100); if(rxChar == '\r' || rxChar == '\n') {
rxBuffer[rxIndex] = '\0';

rxIndex = 0;

cmdReady = 1;
}
else
{
if(rxIndex < sizeof(rxBuffer)-1) {
rxBuffer[rxIndex++] = rxChar; }
}

HAL_UART_Receive_IT(&huart1, &rxChar, 1);
}
}
#MINI Task viết giao thức để giao tiếp với STM32 bằng UART Bluetooth

Mục tiêu là khi nhập lệnh thì STM32 phải phản hồi lại, từ đó phục vụ cho việc tunning không dây
_làm cho nó phản hồi được

Phân tích nguyên nhân (Root Cause Analysis)
1. Xung đột ngắt & HAL Deadlock giữa TIM4 và UART (Nguyên nhân chính) • Hiện trạng: TIM4 ngắt mỗi 10ms (100Hz). Trong callback

HAL_TIM_PeriodElapsedCallback, bạn gọi Control_Loop(), và trong đó có dòng:
C
Motor_SetPWM(3599); // Hoặc các tính toán liên tục
- Lỗi trong Callback Echo:
C
void HAL_UART_RxCpltCallback(UART_HandleTypeDef *huart) {
if(huart->Instance == USART1)
{
// DÙNG HAL_MAX_DELAY TRONG INTERRUPT CONTEXT! HAL_UART_Transmit(&huart1, (uint8_t*) &rxChar, 1, HAL_MAX_DELAY); HAL_UART_Receive_IT(&huart1, (uint8_t*) &rxChar, 1);
}
} • Hậu quả:
1. HAL_UART_Transmit với HAL_MAX_DELAY là hàm blocking (chờ lặp). Gọi hàm blocking ngay bên trong ISR (Interrupt Service Routine) của

UART là điều cấm kỵ. Nếu đường truyền bị nhiễu hoặc HC-05 chưa sẵn sàng nhận, MCU sẽ bị khóa cứng (Deadlock) ngay trong ISR. 2. Mức ưu tiên ngắt (Priority): Nếu TIM4 ngắt đè lên UART khi đang

truyền dữ liệu, UART State của HAL sẽ bị đơ (HAL_BUSY), khiến các lệnh HAL_UART_Receive_IT tiếp theo bị từ chối trả về HAL_ERROR.

### 2. Thiếu ngắt NVIC cho USART1

- Khi cấu hình bằng STM32CubeMX, nếu chỉ chọn USART1 Asynchronous mà chưa tích chọn "USART1 global interrupt" trong mục NVIC Settings, lệnh HAL_UART_Receive_IT() sẽ chỉ chạy đúng 1 lần rồi im lặng mãi mãi vì phần cứng không bao giờ nhảy vào ISR. Từng bước khắc phục & Kiểm chứng (Debug Steps)

Bước 1: Kiểm tra cấu hình NVIC trong CubeMX
Mở file .ioc trong STM32CubeIDE:
1. Vào Connectivity →USART1. 2. Sang tab NVIC Settings. 3. Tích chọn USART1 global interrupt →Enabled. 4. Generate Code lại (Ctrl + S). Bước 2: Sửa lại code Echo Interrupt an toàn (Không Blocking)

Sửa lại hàm HAL_UART_RxCpltCallback để loại bỏ HAL_MAX_DELAY. Thay vào đó, dùng hằng số Timeout ngắn (ví dụ 10ms), hoặc gửi bằng ngắt/xử lý ngoài main:

C
/* USER CODE BEGIN 4 */

void HAL_UART_RxCpltCallback(UART_HandleTypeDef *huart) {
if(huart->Instance == USART1)
{
// 1. Phản hồi ngay ký tự vừa nhận với Timeout an toàn (10ms) thay vì HAL_MAX_DELAY
HAL_UART_Transmit(&huart1, (uint8_t*)&rxChar, 1, 10);

// 2. Kích hoạt lại ngắt nhận 1 byte tiếp theo ngay lập tức HAL_UART_Receive_IT(&huart1, (uint8_t*)&rxChar, 1);
}
}

/* USER CODE END 4 */
Bước 3: Xử lý Tràn bộ đệm & Tự khôi phục lỗi UART (Overrun Error Handling) Một lỗi rất phổ biến khiến UART ngưng nhận dữ liệu trên STM32 HAL là Overrun Error (ORE). Khi ký tự đến quá nhanh mà MCU chưa kịp đọc, HAL sẽ khóa ngắt UART. Thêm hàm callback xử lý lỗi này vào cuối file main.c để tự khôi phục ngắt nếu có

sự cố nhiễu/tràn phím:
C
void HAL_UART_ErrorCallback(UART_HandleTypeDef *huart)
{
if(huart->Instance == USART1)
{
// Xóa cờ lỗi ORE/NE/FE nếu có __HAL_UART_CLEAR_OREFLAG(huart); __HAL_UART_CLEAR_NEFLAG(huart); __HAL_UART_CLEAR_FEFLAG(huart);

// Kích hoạt lại ngắt nhận HAL_UART_Receive_IT(&huart1, (uint8_t*)&rxChar, 1); }

}
Kịch bản Test Echo trên điện thoại
1. Nạp firmware đã cập nhật ở trên vào Blue Pill. 2. Mở ứng dụng Serial Bluetooth trên điện thoại (ví dụ: Serial Bluetooth

Terminal trên Android). 3. Kết nối với HC-05. 4. Gõ từng ký tự (ví dụ: H, E, L, L, O). 5. Kỳ vọng: Mỗi khi bạn bấm 1 phím trên điện thoại, ký tự đó sẽ lập tức xuất

hiện ngược lại trên màn hình app. Nếu Echo hoạt động thành công, ta đã chứng minh 100%: HC-05✓ ⟶
USART1 Hardware✓ ⟶ NVIC Interrupt✓ ⟶ HAL Callback✓

Bạn hãy thực hiện kiểm tra Bước 1 & Bước 2 trên phần cứng. Cho mình biết kết quả Echo (có nhận được ký tự phản hồi từng chữ cái hay chưa) để chúng ta bước sang Tầng Parser & Xây dựng CLI Ring Buffer nhé!

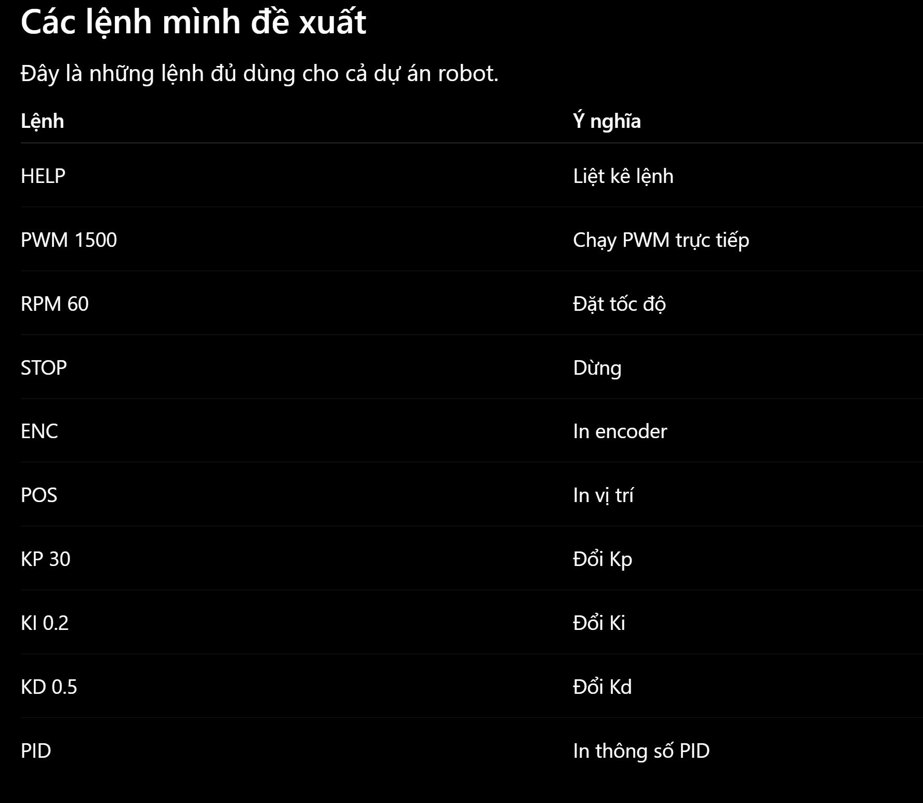
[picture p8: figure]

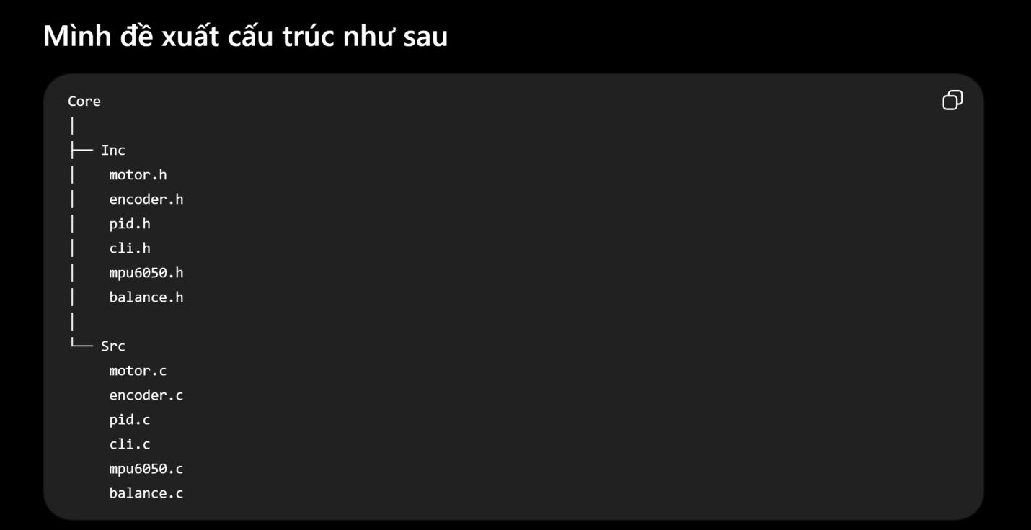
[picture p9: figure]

/* USER CODE BEGIN Header */
/**
******************************************************************************
* @file | : main.c
* @brief | : Main program body
****************************************************************************** * @attention
*
* Copyright (c) 2026 STMicroelectronics. * All rights reserved. *

* This software is licensed under terms that can be found in the LICENSE file * in the root directory of this software component. * If no LICENSE file comes with this software, it is provided AS-IS. *

****************************************************************************** */
/* USER CODE END Header */
/* Includes ------------------------------------------------------------------*/ #include "main.h"

/* Private includes ----------------------------------------------------------*/ /* USER CODE BEGIN Includes */
#include <string.h>

#include <stdio.h>

#include <stdlib.h>

/* USER CODE END Includes */
/* Private typedef -----------------------------------------------------------*/ /* USER CODE BEGIN PTD */
typedef struct
{
float Kp;
float Ki;
float Kd;
float Ts;
float setpoint;
float feedback;
float output;
float error;
float last_error;
float integral;
float derivative;
// Các thành phần kết quả nhân P, I, D riêng biệt float P_term;
float I_term;
float D_term;
float outMax;
float outMin;
float iMax;
float iMin;
} PID_t;
typedef enum {

MODE_MANUAL_PWM = 0, MODE_PID_SPEED = 1
} ControlMode_t;
typedef enum {
PRINT_OFF = 0, PRINT_MONITOR, // In dạng chữ chi tiết có cả Kp, Ki, Kd PRINT_PLOT // In dạng CSV để vẽ đồ thị
} PrintMode_t;
/* USER CODE END PTD */
/* Private define ------------------------------------------------------------*/ /* USER CODE BEGIN PD */
#define ENCODER_CPR 1320.0f

#define SAMPLE_TIME 0.01f

#define RPM_FACTOR (60.0f / (ENCODER_CPR * SAMPLE_TIME))

/* USER CODE END PD */
/* Private macro -------------------------------------------------------------*/ /* USER CODE BEGIN PM */
/* USER CODE END PM */
/* Private variables ---------------------------------------------------------*/ TIM_HandleTypeDef htim2;
TIM_HandleTypeDef htim3;
TIM_HandleTypeDef htim4;
UART_HandleTypeDef huart1;
/* USER CODE BEGIN PV */
// Control & Mode Flags
volatile ControlMode_t control_mode = MODE_MANUAL_PWM; volatile PrintMode_t print_mode = PRINT_OFF;
volatile uint8_t print_flag = 0; // Cờ báo đến giờ in (100ms) int manual_pwm = 0;
volatile int32_t encoder_position = 0;
volatile int16_t encoder_now = 0;
volatile int16_t encoder_old = 0;

volatile int16_t encoder_delta = 0; volatile float encoder_rpm = 0.0f; float target_rpm = 0.0f;
volatile uint32_t timer_cnt = 0; // UART CLI Variables
volatile uint8_t rxChar;
char rxBuffer[32];
uint8_t rxIndex = 0;
volatile uint8_t cmdReady = 0; PID_t Speed_PID;
PID_t Angle_PID;
/* USER CODE END PV */
/* Private function prototypes -----------------------------------------------*/ void SystemClock_Config(void);
static void MX_GPIO_Init(void);
static void MX_TIM2_Init(void);
static void MX_TIM3_Init(void);
static void MX_TIM4_Init(void);
static void MX_USART1_UART_Init(void);
/* USER CODE BEGIN PFP */
void HAL_TIM_MspPostInit(TIM_HandleTypeDef *htim); void Motor_SetPWM(int pwm);
void Encoder_Update(void);
void PID_Init(PID_t *pid);
float PID_Update(PID_t *pid); void Process_Command(void);
void Process_Print(void);
/* USER CODE END PFP */
/* Private user code ---------------------------------------------------------*/ /* USER CODE BEGIN 0 */
/* USER CODE END 0 */
/**
* @brief The application entry point.

* @retval int
*/
int main(void)
{
/* USER CODE BEGIN 1 */
/* USER CODE END 1 */
/* MCU Configuration--------------------------------------------------------*/ /* Reset of all peripherals, Initializes the Flash interface and the Systick. */ HAL_Init();
/* USER CODE BEGIN Init */
/* USER CODE END Init */
/* Configure the system clock */ SystemClock_Config();
/* USER CODE BEGIN SysInit */
/* USER CODE END SysInit */
/* Initialize all configured peripherals */ MX_GPIO_Init();
MX_TIM2_Init();
MX_TIM3_Init();
MX_TIM4_Init();
MX_USART1_UART_Init();
/* USER CODE BEGIN 2 */
// Khởi động các kênh xung PWM trên TIMER 2 HAL_TIM_PWM_Start(&htim2, TIM_CHANNEL_1); HAL_TIM_PWM_Start(&htim2, TIM_CHANNEL_2);
// Bật chân STBY để kích hoạt IC driver TB6612 (PA4) HAL_GPIO_WritePin(GPIOA, GPIO_PIN_4, GPIO_PIN_SET); // Khởi động Encoder TIM3

HAL_TIM_Encoder_Start(&htim3, TIM_CHANNEL_ALL); encoder_old = (int16_t)__HAL_TIM_GET_COUNTER(&htim3); // Cấu hình PID Speed mặc định
Speed_PID.Kp = 40.0f;
Speed_PID.Ki = 0.0f;
Speed_PID.Kd = 0.0f;
Speed_PID.Ts = SAMPLE_TIME; Speed_PID.outMax = 3599.0f; Speed_PID.outMin = -3599.0f; Speed_PID.iMax = 1000.0f;
Speed_PID.iMin = -1000.0f; PID_Init(&Speed_PID);
// Bắt đầu Timer ngắt chu kỳ 10ms (100Hz) HAL_TIM_Base_Start_IT(&htim4);
// Kích hoạt ngắt nhận UART1 (1 byte) HAL_UART_Receive_IT(&huart1, (uint8_t*)&rxChar, 1); /* USER CODE END 2 */
/* Infinite loop */
/* USER CODE BEGIN WHILE */
while (1)
{
/* USER CODE END WHILE */
/* USER CODE BEGIN 3 */
// 1. Xử lý lệnh từ UART / Bluetooth if (cmdReady)
{
cmdReady = 0;
Process_Command();
}
// 2. Xuất dữ liệu Monitor / Plotter ngoài luồng ngắt (chu kỳ 100ms) Process_Print();
}
/* USER CODE END 3 */
}

/**
* @brief System Clock Configuration * @retval None
*/
void SystemClock_Config(void)
{
RCC_OscInitTypeDef RCC_OscInitStruct = {0};
RCC_ClkInitTypeDef RCC_ClkInitStruct = {0};
/** Initializes the RCC Oscillators according to the specified parameters * in the RCC_OscInitTypeDef structure. */
RCC_OscInitStruct.OscillatorType = RCC_OSCILLATORTYPE_HSE; RCC_OscInitStruct.HSEState = RCC_HSE_ON; RCC_OscInitStruct.HSEPredivValue = RCC_HSE_PREDIV_DIV1; RCC_OscInitStruct.HSIState = RCC_HSI_ON; RCC_OscInitStruct.PLL.PLLState = RCC_PLL_ON; RCC_OscInitStruct.PLL.PLLSource = RCC_PLLSOURCE_HSE; RCC_OscInitStruct.PLL.PLLMUL = RCC_PLL_MUL9;
if (HAL_RCC_OscConfig(&RCC_OscInitStruct) != HAL_OK) {
Error_Handler();
}
/** Initializes the CPU, AHB and APB buses clocks
*/
RCC_ClkInitStruct.ClockType = RCC_CLOCKTYPE_HCLK|RCC_CLOCKTYPE_SYSCLK |RCC_CLOCKTYPE_PCLK1|RCC_CLOCKTYPE_PCLK2; RCC_ClkInitStruct.SYSCLKSource = RCC_SYSCLKSOURCE_PLLCLK; RCC_ClkInitStruct.AHBCLKDivider = RCC_SYSCLK_DIV1; RCC_ClkInitStruct.APB1CLKDivider = RCC_HCLK_DIV2; RCC_ClkInitStruct.APB2CLKDivider = RCC_HCLK_DIV1;
if (HAL_RCC_ClockConfig(&RCC_ClkInitStruct, FLASH_LATENCY_2) != HAL_OK) {
Error_Handler();
}
}

/**
* @brief TIM2 Initialization Function * @param None
* @retval None
*/
static void MX_TIM2_Init(void)
{
/* USER CODE BEGIN TIM2_Init 0 */
/* USER CODE END TIM2_Init 0 */ TIM_ClockConfigTypeDef sClockSourceConfig = {0}; TIM_MasterConfigTypeDef sMasterConfig = {0}; TIM_OC_InitTypeDef sConfigOC = {0};
/* USER CODE BEGIN TIM2_Init 1 */
/* USER CODE END TIM2_Init 1 */
htim2.Instance = TIM2;
htim2.Init.Prescaler = 0;
htim2.Init.CounterMode = TIM_COUNTERMODE_UP; htim2.Init.Period = 3599;
htim2.Init.ClockDivision = TIM_CLOCKDIVISION_DIV1; htim2.Init.AutoReloadPreload = TIM_AUTORELOAD_PRELOAD_ENABLE; if (HAL_TIM_Base_Init(&htim2) != HAL_OK)
{
Error_Handler();
}
sClockSourceConfig.ClockSource = TIM_CLOCKSOURCE_INTERNAL;
if (HAL_TIM_ConfigClockSource(&htim2, &sClockSourceConfig) != HAL_OK) {
Error_Handler();
}
if (HAL_TIM_PWM_Init(&htim2) != HAL_OK) {
Error_Handler();
}
sMasterConfig.MasterOutputTrigger = TIM_TRGO_RESET; sMasterConfig.MasterSlaveMode = TIM_MASTERSLAVEMODE_DISABLE;

if (HAL_TIMEx_MasterConfigSynchronization(&htim2, &sMasterConfig) != HAL_OK) {
Error_Handler();
}
sConfigOC.OCMode = TIM_OCMODE_PWM1; sConfigOC.Pulse = 0;
sConfigOC.OCPolarity = TIM_OCPOLARITY_HIGH;
sConfigOC.OCFastMode = TIM_OCFAST_DISABLE;
if (HAL_TIM_PWM_ConfigChannel(&htim2, &sConfigOC, TIM_CHANNEL_1) != HAL_OK) {
Error_Handler();
}
if (HAL_TIM_PWM_ConfigChannel(&htim2, &sConfigOC, TIM_CHANNEL_2) != HAL_OK) {
Error_Handler();
}
/* USER CODE BEGIN TIM2_Init 2 */ /* USER CODE END TIM2_Init 2 */ HAL_TIM_MspPostInit(&htim2);
}
/**
* @brief TIM3 Initialization Function * @param None
* @retval None
*/
static void MX_TIM3_Init(void)
{
/* USER CODE BEGIN TIM3_Init 0 */
/* USER CODE END TIM3_Init 0 */ TIM_Encoder_InitTypeDef sConfig = {0}; TIM_MasterConfigTypeDef sMasterConfig = {0};

/* USER CODE BEGIN TIM3_Init 1 */ /* USER CODE END TIM3_Init 1 */
htim3.Instance = TIM3;
htim3.Init.Prescaler = 0;
htim3.Init.CounterMode = TIM_COUNTERMODE_UP; htim3.Init.Period = 65535;
htim3.Init.ClockDivision = TIM_CLOCKDIVISION_DIV1; htim3.Init.AutoReloadPreload = TIM_AUTORELOAD_PRELOAD_DISABLE; sConfig.EncoderMode = TIM_ENCODERMODE_TI12; sConfig.IC1Polarity = TIM_ICPOLARITY_RISING;
sConfig.IC1Selection = TIM_ICSELECTION_DIRECTTI; sConfig.IC1Prescaler = TIM_ICPSC_DIV1; sConfig.IC1Filter = 10;
sConfig.IC2Polarity = TIM_ICPOLARITY_RISING; sConfig.IC2Selection = TIM_ICSELECTION_DIRECTTI; sConfig.IC2Prescaler = TIM_ICPSC_DIV1; sConfig.IC2Filter = 10;
if (HAL_TIM_Encoder_Init(&htim3, &sConfig) != HAL_OK) {
Error_Handler();
}
sMasterConfig.MasterOutputTrigger = TIM_TRGO_RESET; sMasterConfig.MasterSlaveMode = TIM_MASTERSLAVEMODE_DISABLE; if (HAL_TIMEx_MasterConfigSynchronization(&htim3, &sMasterConfig) != HAL_OK) {
Error_Handler();
}
/* USER CODE BEGIN TIM3_Init 2 */ /* USER CODE END TIM3_Init 2 */ }
/**
* @brief TIM4 Initialization Function * @param None
* @retval None

*/
static void MX_TIM4_Init(void)
{
/* USER CODE BEGIN TIM4_Init 0 */
/* USER CODE END TIM4_Init 0 */ TIM_ClockConfigTypeDef sClockSourceConfig = {0}; TIM_MasterConfigTypeDef sMasterConfig = {0}; /* USER CODE BEGIN TIM4_Init 1 */
/* USER CODE END TIM4_Init 1 */
htim4.Instance = TIM4;
htim4.Init.Prescaler = 7199;
htim4.Init.CounterMode = TIM_COUNTERMODE_UP; htim4.Init.Period = 99;
htim4.Init.ClockDivision = TIM_CLOCKDIVISION_DIV1; htim4.Init.AutoReloadPreload = TIM_AUTORELOAD_PRELOAD_DISABLE; if (HAL_TIM_Base_Init(&htim4) != HAL_OK)
{
Error_Handler();
}
sClockSourceConfig.ClockSource = TIM_CLOCKSOURCE_INTERNAL;
if (HAL_TIM_ConfigClockSource(&htim4, &sClockSourceConfig) != HAL_OK) {
Error_Handler();
}
sMasterConfig.MasterOutputTrigger = TIM_TRGO_RESET; sMasterConfig.MasterSlaveMode = TIM_MASTERSLAVEMODE_DISABLE; if (HAL_TIMEx_MasterConfigSynchronization(&htim4, &sMasterConfig) != HAL_OK) {
Error_Handler();
}
/* USER CODE BEGIN TIM4_Init 2 */ /* USER CODE END TIM4_Init 2 */

}
/**
* @brief USART1 Initialization Function * @param None
* @retval None
*/
static void MX_USART1_UART_Init(void) {
/* USER CODE BEGIN USART1_Init 0 */ /* USER CODE END USART1_Init 0 */ /* USER CODE BEGIN USART1_Init 1 */ /* USER CODE END USART1_Init 1 */ huart1.Instance = USART1;
huart1.Init.BaudRate = 115200; huart1.Init.WordLength = UART_WORDLENGTH_8B; huart1.Init.StopBits = UART_STOPBITS_1; huart1.Init.Parity = UART_PARITY_NONE; huart1.Init.Mode = UART_MODE_TX_RX; huart1.Init.HwFlowCtl = UART_HWCONTROL_NONE; huart1.Init.OverSampling = UART_OVERSAMPLING_16; if (HAL_UART_Init(&huart1) != HAL_OK)
{
Error_Handler();
}
/* USER CODE BEGIN USART1_Init 2 */ /* USER CODE END USART1_Init 2 */ }
/**
* @brief GPIO Initialization Function * @param None
* @retval None
*/

static void MX_GPIO_Init(void)
{
GPIO_InitTypeDef GPIO_InitStruct = {0}; /* USER CODE BEGIN MX_GPIO_Init_1 */ /* USER CODE END MX_GPIO_Init_1 */ /* GPIO Ports Clock Enable */
__HAL_RCC_GPIOD_CLK_ENABLE(); __HAL_RCC_GPIOA_CLK_ENABLE(); __HAL_RCC_GPIOB_CLK_ENABLE();

/*Configure GPIO pin Output Level */
HAL_GPIO_WritePin(GPIOA, GPIO_PIN_2|GPIO_PIN_3|GPIO_PIN_4|GPIO_PIN_5 |GPIO_PIN_6, GPIO_PIN_RESET); /*Configure GPIO pins : PA2 PA3 PA4 PA5
PA6 */
GPIO_InitStruct.Pin = GPIO_PIN_2|GPIO_PIN_3|GPIO_PIN_4|GPIO_PIN_5 |GPIO_PIN_6;
GPIO_InitStruct.Mode = GPIO_MODE_OUTPUT_PP; GPIO_InitStruct.Pull = GPIO_NOPULL;
GPIO_InitStruct.Speed = GPIO_SPEED_FREQ_LOW; HAL_GPIO_Init(GPIOA, &GPIO_InitStruct);
/* USER CODE BEGIN MX_GPIO_Init_2 */
/* USER CODE END MX_GPIO_Init_2 */
}
/* USER CODE BEGIN 4 */
void Motor_SetPWM(int pwm)
{
if(pwm > 3599) pwm = 3599; if(pwm < -3599) pwm = -3599;
if(pwm >= 0)
{
HAL_GPIO_WritePin(GPIOA, GPIO_PIN_5, GPIO_PIN_SET);

HAL_GPIO_WritePin(GPIOA, GPIO_PIN_6, GPIO_PIN_RESET); __HAL_TIM_SET_COMPARE(&htim2, TIM_CHANNEL_2, pwm); }
else
{
HAL_GPIO_WritePin(GPIOA, GPIO_PIN_5, GPIO_PIN_RESET); HAL_GPIO_WritePin(GPIOA, GPIO_PIN_6, GPIO_PIN_SET); __HAL_TIM_SET_COMPARE(&htim2, TIM_CHANNEL_2, -pwm); }
}
void Encoder_Update(void)
{
encoder_now = (int16_t)__HAL_TIM_GET_COUNTER(&htim3); encoder_delta = encoder_now - encoder_old;
encoder_old = encoder_now;
encoder_position += encoder_delta;
encoder_rpm = (float)encoder_delta * RPM_FACTOR; }
void Control_Loop(void)
{
Encoder_Update();
if (control_mode == MODE_PID_SPEED) {
Speed_PID.feedback = encoder_rpm; Speed_PID.setpoint = target_rpm; float out = PID_Update(&Speed_PID); Motor_SetPWM((int)out);
}
else
{
Motor_SetPWM(manual_pwm);
}
}
void HAL_TIM_PeriodElapsedCallback(TIM_HandleTypeDef *htim) {

if(htim->Instance == TIM4)
{
timer_cnt++;
Control_Loop(); // Tính toán PID mỗi 10ms
// Bật cờ xuất dữ liệu UART sau mỗi 100ms (10 x 10ms) static uint8_t print_cnt = 0;
if (++print_cnt >= 10)
{
print_cnt = 0;
if (print_mode != PRINT_OFF) {
print_flag = 1;
}
}
}
}
void PID_Init(PID_t *pid)
{
pid->error = 0.0f;
pid->last_error = 0.0f;
pid->integral = 0.0f;
pid->derivative = 0.0f;
pid->P_term = 0.0f;
pid->I_term = 0.0f;
pid->D_term = 0.0f;
pid->output = 0.0f;
pid->setpoint = 0.0f;
pid->feedback = 0.0f;
}
float PID_Update(PID_t *pid)
{
pid->error = pid->setpoint - pid->feedback;
// Tích phân (Integral)
pid->integral += pid->error * pid->Ts;
if(pid->integral > pid->iMax) pid->integral = pid->iMax; if(pid->integral < pid->iMin) pid->integral = pid->iMin;

// Vi phân (Derivative)
pid->derivative = (pid->error - pid->last_error) / pid->Ts; // Tính riêng từng thành phần
pid->P_term = pid->Kp * pid->error;
pid->I_term = pid->Ki * pid->integral;
pid->D_term = pid->Kd * pid->derivative;
// Tổng ngõ ra
pid->output = pid->P_term + pid->I_term + pid->D_term; // Bão hòa ngõ ra PWM
if(pid->output > pid->outMax) pid->output = pid->outMax; if(pid->output < pid->outMin) pid->output = pid->outMin; pid->last_error = pid->error;
return pid->output;
}
/*======================================================= =============
* UART MONITOR / PLOTTER PRINT PROCESSOR (Chạy trong vòng lặp while(1)) *======================================================= ============= */
void Process_Print(void)
{
if (!print_flag) return;
print_flag = 0; // Reset cờ
char msg[160];
if (print_mode == PRINT_MONITOR)
{
// Hiển thị cả Kp Ki Kd | Target, Real, Err | P, I, D | Output PWM
sprintf(msg, "[Kp:%.1f Ki:%.1f Kd:%.1f] | T:%5.1f R:%5.1f E:%5.1f | P:%6.1f
I:%6.1f D:%6.1f | OUT:%5.0f\r\n",

Speed_PID.Kp, Speed_PID.Ki, Speed_PID.Kd, target_rpm, encoder_rpm, Speed_PID.error, Speed_PID.P_term, Speed_PID.I_term, Speed_PID.D_term, Speed_PID.output);

HAL_UART_Transmit(&huart1, (uint8_t*)msg, strlen(msg), 30); }
else if (print_mode == PRINT_PLOT)
{
// Định dạng CSV dành cho Serial Plotter vẽ 5 đường đồng thời: // Cú pháp: Target, RPM, P_term, I_term, D_term
sprintf(msg, "%.1f,%.1f,%.1f,%.1f,%.1f\r\n", target_rpm, encoder_rpm, Speed_PID.P_term, Speed_PID.I_term, Speed_PID.D_term);

HAL_UART_Transmit(&huart1, (uint8_t*)msg, strlen(msg), 20);
}
}
/*======================================================= =============
* CLI COMMAND PROCESSOR
*======================================================= ============= */
void Process_Command(void)
{
char msg[128];
// --- Lệnh HELP ---
if(strcmp(rxBuffer, "HELP") == 0)
{
char *help_text =
"\r\n========== COMMAND LIST ==========\r\n" "HELP : Show command menu\r\n"
"PWM xxx : Set manual PWM (-3599 to 3599)\r\n" "RPM xxx : Set target RPM (Enable PID)\r\n"

"STOP : Stop motor & reset mode\r\n"
"STATUS : Show Mode, RPM & Encoder\r\n"
"MONITOR : Stream Kp,Ki,Kd | T,R,E | P,I,D | OUT\r\n"
"PLOT : Stream CSV (Target,RPM,P,I,D) for Plotter\r\n" "STOPMON : Stop streaming data\r\n"
"ENC : Show Encoder position\r\n"
"KP xxx : Set Speed PID Kp\r\n"
"KI xxx : Set Speed PID Ki\r\n"
"KD xxx : Set Speed PID Kd\r\n" "==================================\r\n"; HAL_UART_Transmit(&huart1, (uint8_t*)help_text, strlen(help_text), 100); }
// --- Lệnh PWM xxx --- else if(strncmp(rxBuffer, "PWM ", 4) == 0)
{
int val = 0;
if(sscanf(rxBuffer + 4, "%d", &val) == 1) {
control_mode = MODE_MANUAL_PWM;
manual_pwm = val;
Motor_SetPWM(manual_pwm);
sprintf(msg, "\r\n[MODE] Manual PWM = %d\r\n", manual_pwm); HAL_UART_Transmit(&huart1, (uint8_t*)msg, strlen(msg), 100);
}
}
// --- Lệnh RPM xxx --- else if(strncmp(rxBuffer, "RPM ", 4) == 0)
{
float val = 0.0f;
if(sscanf(rxBuffer + 4, "%f", &val) == 1) {
control_mode = MODE_PID_SPEED;
target_rpm = val;
sprintf(msg, "\r\n[MODE] PID Speed Target = %.2f RPM\r\n", target_rpm); HAL_UART_Transmit(&huart1, (uint8_t*)msg, strlen(msg), 100);
}
}

// --- Lệnh MONITOR --- else if(strcmp(rxBuffer, "MONITOR") == 0)
{
print_mode = PRINT_MONITOR;
char *m = "\r\n[MONITOR ON - Full PID Inspection]\r\n"; HAL_UART_Transmit(&huart1, (uint8_t*)m, strlen(m), 50); }
// --- Lệnh PLOT --- else if(strcmp(rxBuffer, "PLOT") == 0)
{
print_mode = PRINT_PLOT;
}
// --- Lệnh STOPMON --- else if(strcmp(rxBuffer, "STOPMON") == 0) {
print_mode = PRINT_OFF;
char *m = "\r\n[MONITOR OFF]\r\n"; HAL_UART_Transmit(&huart1, (uint8_t*)m, strlen(m), 50); }
// --- Lệnh STOP --- else if(strcmp(rxBuffer, "STOP") == 0)
{
control_mode = MODE_MANUAL_PWM; manual_pwm = 0;
target_rpm = 0.0f;
Motor_SetPWM(0);
sprintf(msg, "\r\nMotor Stopped!\r\n"); HAL_UART_Transmit(&huart1, (uint8_t*)msg, strlen(msg), 100); }
// --- Lệnh STATUS --- else if(strcmp(rxBuffer, "STATUS") == 0)
{
sprintf(msg, "\r\nMode: %s | PWM: %d | Target RPM: %.1f | Current
RPM: %.1f | Pos: %ld\r\n", (control_mode == MODE_PID_SPEED) ? "PID_SPEED" : "MANUAL_PWM", manual_pwm, target_rpm, encoder_rpm, (long)encoder_position);

HAL_UART_Transmit(&huart1, (uint8_t*)msg, strlen(msg), 100);
}
// --- Lệnh ENC ---else if(strcmp(rxBuffer, "ENC") == 0 || strcmp(rxBuffer, "POS") == 0) {
sprintf(msg, "\r\nEncoder Pos = %ld\r\n", (long)encoder_position); HAL_UART_Transmit(&huart1, (uint8_t*)msg, strlen(msg), 100);
}
// --- Lệnh chỉnh PID Kp --- else if(strncmp(rxBuffer, "KP ", 3) == 0)
{
float val = 0.0f;
if(sscanf(rxBuffer + 3, "%f", &val) == 1)
{
Speed_PID.Kp = val;
sprintf(msg, "\r\nKp set to %.3f\r\n", Speed_PID.Kp); HAL_UART_Transmit(&huart1, (uint8_t*)msg, strlen(msg), 100); }
}
// --- Lệnh chỉnh PID Ki --- else if(strncmp(rxBuffer, "KI ", 3) == 0)
{
float val = 0.0f;
if(sscanf(rxBuffer + 3, "%f", &val) == 1)
{
Speed_PID.Ki = val;
sprintf(msg, "\r\nKi set to %.3f\r\n", Speed_PID.Ki); HAL_UART_Transmit(&huart1, (uint8_t*)msg, strlen(msg), 100); }
}
// --- Lệnh chỉnh PID Kd --- else if(strncmp(rxBuffer, "KD ", 3) == 0)
{
float val = 0.0f;
if(sscanf(rxBuffer + 3, "%f", &val) == 1)
{
Speed_PID.Kd = val;
sprintf(msg, "\r\nKd set to %.3f\r\n", Speed_PID.Kd); HAL_UART_Transmit(&huart1, (uint8_t*)msg, strlen(msg), 100); }
}
// --- Lệnh không xác định --- else

{
sprintf(msg, "\r\nUnknown Command: %s\r\n", rxBuffer); HAL_UART_Transmit(&huart1, (uint8_t*)msg, strlen(msg), 100);
}
}
/*======================================================= =============
* UART CLI RECEIVER & CALLBACKS *======================================================= ============= */
void HAL_UART_RxCpltCallback(UART_HandleTypeDef *huart)
{
if(huart->Instance == USART1)
{
// 1. Echo ký tự vừa gõ
HAL_UART_Transmit(&huart1, (uint8_t*)&rxChar, 1, 10); // 2. Kiểm tra ký tự kết thúc dòng
if (rxChar == '\r' || rxChar == '\n')
{
if (rxIndex > 0)
{
rxBuffer[rxIndex] = '\0';
cmdReady = 1;
rxIndex = 0;
}
}
else
{
if (rxIndex < (sizeof(rxBuffer) - 1)) {
rxBuffer[rxIndex++] = rxChar; }
else
{
rxIndex = 0; // Chống tràn bộ đệm }

}
// 3. Tiếp tục lắng nghe ký tự tiếp theo HAL_UART_Receive_IT(&huart1, (uint8_t*)&rxChar, 1); }
}
void HAL_UART_ErrorCallback(UART_HandleTypeDef *huart) {
if(huart->Instance == USART1)
{ __HAL_UART_CLEAR_OREFLAG(huart); __HAL_UART_CLEAR_NEFLAG(huart); __HAL_UART_CLEAR_FEFLAG(huart);

HAL_UART_Receive_IT(&huart1, (uint8_t*)&rxChar, 1); }
}
/* USER CODE END 4 */
/**
* @brief This function is executed in case of error occurrence. * @retval None */
void Error_Handler(void)
{
/* USER CODE BEGIN Error_Handler_Debug */ __disable_irq();
while (1)
{
}
/* USER CODE END Error_Handler_Debug */ }
#ifdef USE_FULL_ASSERT

/**
* @brief Reports the name of the source file and the source line number * where the assert_param error has occurred. * @param file: pointer to the source file name
* @param line: assert_param error line source number

* @retval None
*/
void assert_failed(uint8_t *file, uint32_t line) {
/* USER CODE BEGIN 6 */
/* USER CODE END 6 */
}
#endif /* USE_FULL_ASSERT */

#TASK 4: Angle PID and MPU control + filter #dùng được MPU:

MPU | STM32
VCC | 5V
GND | GND
SCL | PB6 (I2C1_SCL)
SDA | PB7 (I2C1_SDA)
Cấu hình CubeMX
Hãy thiết lập:
I2C1
- Mode: I2C
- SCL: PB6
- SDA: PB7
- Clock Speed: 100000 Hz
- Addressing Mode: 7-bit
- Dual Address: Disable
- General Call: Disable
- No Stretch: Disable
RCC
- HSE nếu bạn đang dùng thạch anh ngoài (giữ nguyên như project hiện tại). NVIC
- Chưa cần bật Interrupt cho I2C. DMA
- Chưa cần. Sau đó chúng ta sẽ làm đúng quy trình

Bước 1: Kiểm tra thiết bị có tồn tại trên bus I2C không. HAL_I2C_IsDeviceReady(...) ↓
Nếu thành công:
MPU6050 Found
↓
Bước 2: Đọc thanh ghi WHO_AM_I. ↓ Bước 3: Đánh thức MPU6050. ↓ Bước 4: Đọc gia tốc và con quay. ↓ Bước 5: Tính góc.

Bước 1:
B1: Thêm biến
Trong /* USER CODE BEGIN PV */ I2C_HandleTypeDef hi2c1;
uint8_t txBuf[100];
HAL_StatusTypeDef mpuStatus;
Lưu ý: hi2c1 thường đã được CubeMX tạo trong main.c. Nếu đã có thì không khai báo lại, chỉ thêm txBuf và mpuStatus. B2: Địa chỉ I2C của MPU6050

Thêm vào phần /* USER CODE BEGIN PD */
#define MPU6050_ADDR (0x68 << 1)

Tại sao lại << 1?
- Địa chỉ thật của MPU6050 là 0x68
- HAL của STM32 yêu cầu địa chỉ 7-bit dịch trái 1 bit nên:
0x68 << 1 = 0xD0
B3: Sau MX_I2C1_Init();
Trong main()
MX_GPIO_Init();
MX_USART1_UART_Init();
MX_I2C1_Init();
thêm:
HAL_Delay(100);
mpuStatus = HAL_I2C_IsDeviceReady(&hi2c1, MPU6050_ADDR, 3, 100); if(mpuStatus == HAL_OK)
{
sprintf((char*)txBuf, "MPU6050 Found!\r\n");
}
else
{
sprintf((char*)txBuf, "MPU6050 Not Found!\r\n"); }

HAL_UART_Transmit(&huart1, txBuf, strlen((char*)txBuf), HAL_MAX_DELAY);

Bước 2: Đọc thanh ghi WHO_AM_I
Thanh ghi này giống như "chứng minh thư" của MPU6050. • Địa chỉ thanh ghi: 0x75
- Giá trị mong đợi: 0x68
Thêm biến
Trong USER CODE BEGIN PV
uint8_t who_am_i;
Đọc thanh ghi
Ngay sau khi in "MPU Found" (vẫn trong USER CODE BEGIN 2): HAL_I2C_Mem_Read(&hi2c1, MPU6050_ADDR, 0x75, I2C_MEMADD_SIZE_8BIT, &who_am_i, 1, HAL_MAX_DELAY);

sprintf((char*)txBuf, "WHO_AM_I = 0x%02X\r\n", who_am_i); HAL_UART_Transmit(&huart1, txBuf, strlen((char*)txBuf), HAL_MAX_DELAY);

Kết quả mong đợi
Bluetooth sẽ hiện:
MPU6050 Found!
WHO_AM_I = 0x68
Nếu đúng 0x68 thì gần như chắc chắn chúng ta đang giao tiếp với đúng MPU6050. Đánh thức (Wake Up) MPU6050

Bước 1: Tạo biến
Trong USER CODE BEGIN PV:
uint8_t data;
Bước 2: Ghi vào thanh ghi
Ngay sau khi đọc WHO_AM_I thành công: data = 0x00;

HAL_I2C_Mem_Write(&hi2c1, MPU6050_ADDR, 0x6B, I2C_MEMADD_SIZE_8BIT, &data, 1, HAL_MAX_DELAY);

Đoạn này nghĩa là:
Ghi giá trị 0x00 vào thanh ghi 0x6B. Bước 3: Kiểm tra lại

Để chắc chắn việc ghi thành công, ta đọc lại chính thanh ghi đó: HAL_I2C_Mem_Read(&hi2c1, MPU6050_ADDR, 0x6B, I2C_MEMADD_SIZE_8BIT, &data, 1, HAL_MAX_DELAY);

sprintf((char*)txBuf, "PWR_MGMT_1 = 0x%02X\r\n", data); HAL_UART_Transmit(&huart1, txBuf, strlen((char*)txBuf), HAL_MAX_DELAY);

Nếu mọi thứ đúng, Bluetooth sẽ hiện:
MPU6050 Found!
WHO_AM_I = 0x68
PWR_MGMT_1 = 0x00

MPU6050 lưu dữ liệu ở đâu?
Các thanh ghi từ 0x3B đến 0x48 chứa toàn bộ dữ liệu cảm biến: Thanh ghi Dữ liệu
0x3B-0x3C Accel X
0x3D-0x3E Accel Y
0x3F-0x40 Accel Z

Thanh ghi Dữ liệu
0x41-0x42 Temperature
0x43-0x44 Gyro X
0x45-0x46 Gyro Y
0x47-0x48 Gyro Z
Mỗi giá trị đều là 16-bit, nên cần đọc 2 byte rồi ghép lại. #code đang gặp lỗi nè:

/* USER CODE BEGIN Header */
/**
******************************************************************************
* @file | : main.c
* @brief | : Main program body
****************************************************************************** * @attention
*
* Copyright (c) 2026 STMicroelectronics. * All rights reserved. *

* This software is licensed under terms that can be found in the LICENSE file * in the root directory of this software component. * If no LICENSE file comes with this software, it is provided AS-IS. *

****************************************************************************** */
/* USER CODE END Header */
/* Includes ------------------------------------------------------------------*/ #include "main.h"
/* Private includes ----------------------------------------------------------*/ /* USER CODE BEGIN Includes */
#include <string.h>

#include <stdio.h>

#include <stdlib.h>

#include <math.h>

/* USER CODE END Includes */
/* Private typedef -----------------------------------------------------------*/

/* USER CODE BEGIN PTD */
typedef struct
{
float Kp;
float Ki;
float Kd;
float Ts;
float setpoint;
float feedback;
float output;
float error;
float last_error;
float integral;
float derivative;
// Các thành phần kết quả nhân P, I, D riêng biệt float P_term;
float I_term;
float D_term;
float outMax;
float outMin;
float iMax;
float iMin;
} PID_t;
typedef enum {
MODE_MANUAL_PWM = 0, MODE_PID_SPEED = 1
} ControlMode_t;
typedef enum {
PRINT_OFF = 0, PRINT_MONITOR, // In dạng chữ chi tiết có cả Kp, Ki, Kd PRINT_PLOT // In dạng CSV để vẽ đồ thị

} PrintMode_t;
/* USER CODE END PTD */
/* Private define ------------------------------------------------------------*/ /* USER CODE BEGIN PD */
#define ENCODER_CPR 1320.0f

#define SAMPLE_TIME 0.01f

#define RPM_FACTOR (60.0f / (ENCODER_CPR * SAMPLE_TIME)) #define MPU6050_ADDR (0x68 << 1)

#define M_PI 3.14159265358979323846

#define DT 0.01f

/* USER CODE END PD */
/* Private macro -------------------------------------------------------------*/ /* USER CODE BEGIN PM */
/* USER CODE END PM */
/* Private variables ---------------------------------------------------------*/ I2C_HandleTypeDef hi2c1;
TIM_HandleTypeDef htim2;
TIM_HandleTypeDef htim3;
TIM_HandleTypeDef htim4;
UART_HandleTypeDef huart1;
/* USER CODE BEGIN PV */
// Control & Mode Flags
volatile ControlMode_t control_mode = MODE_MANUAL_PWM; volatile PrintMode_t print_mode = PRINT_OFF;
volatile uint8_t print_flag = 0; // Cờ báo đến giờ in (100ms) int manual_pwm = 0;
volatile int32_t encoder_position = 0;
volatile int16_t encoder_now = 0;
volatile int16_t encoder_old = 0; volatile int16_t encoder_delta = 0; volatile float encoder_rpm = 0.0f;

float target_rpm = 0.0f;
volatile uint32_t timer_cnt = 0; // UART CLI Variables
volatile uint8_t rxChar;
char rxBuffer[32];
uint8_t rxIndex = 0;
volatile uint8_t cmdReady = 0; PID_t Speed_PID;
PID_t Angle_PID;
// MPU Variables
uint8_t txBuf[100];
HAL_StatusTypeDef mpuStatus; uint8_t who_am_i;
uint8_t data;
uint8_t mpuData[14];
int16_t AccX;
int16_t AccY;
int16_t AccZ;
int16_t GyroX;
int16_t GyroY;
int16_t GyroZ;
int16_t Temp;
float Ax;
float Ay;
float Az;
float Gx;
float Gy;
float Gz;
float AccAngle = 0.0f;
float PitchAcc = 0.0f;
float Roll = 0.0f;

float RollAcc = 0.0f;
float RollGyro = 0.0f;
float GxOffset = 0.0f;
/* USER CODE END PV */
/* Private function prototypes -----------------------------------------------*/ void SystemClock_Config(void);
static void MX_GPIO_Init(void);
static void MX_TIM2_Init(void);
static void MX_TIM3_Init(void);
static void MX_TIM4_Init(void);
static void MX_USART1_UART_Init(void);
static void MX_I2C1_Init(void);
/* USER CODE BEGIN PFP */
void HAL_TIM_MspPostInit(TIM_HandleTypeDef *htim); void Motor_SetPWM(int pwm);
void Encoder_Update(void);
void PID_Init(PID_t *pid);
float PID_Update(PID_t *pid);
void Process_Command(void);
void Process_Print(void);
void MPU6050_GyroCalibration(void);
/* USER CODE END PFP */
/* Private user code ---------------------------------------------------------*/ /* USER CODE BEGIN 0 */
/* USER CODE END 0 */
/**
* @brief The application entry point. * @retval int */
int main(void)
{
/* USER CODE BEGIN 1 */
/* USER CODE END 1 */

/* MCU Configuration--------------------------------------------------------*/ /* Reset of all peripherals, Initializes the Flash interface and the Systick. */ HAL_Init();
/* USER CODE BEGIN Init */
/* USER CODE END Init */
/* Configure the system clock */ SystemClock_Config();
/* USER CODE BEGIN SysInit */
/* USER CODE END SysInit */
/* Initialize all configured peripherals */ MX_GPIO_Init();
MX_TIM2_Init();
MX_TIM3_Init();
MX_TIM4_Init();
MX_USART1_UART_Init();
MX_I2C1_Init();
/* USER CODE BEGIN 2 */
// Khởi động các kênh xung PWM trên TIMER 2 HAL_TIM_PWM_Start(&htim2, TIM_CHANNEL_1); HAL_TIM_PWM_Start(&htim2, TIM_CHANNEL_2);
// Bật chân STBY để kích hoạt IC driver TB6612 (PA4) HAL_GPIO_WritePin(GPIOA, GPIO_PIN_4, GPIO_PIN_SET); // Khởi động Encoder TIM3
HAL_TIM_Encoder_Start(&htim3, TIM_CHANNEL_ALL); encoder_old = (int16_t)__HAL_TIM_GET_COUNTER(&htim3); // Cấu hình PID Speed mặc định
Speed_PID.Kp = 40.0f;
Speed_PID.Ki = 0.0f;
Speed_PID.Kd = 0.0f;
Speed_PID.Ts = SAMPLE_TIME;

Speed_PID.outMax = 3599.0f; Speed_PID.outMin = -3599.0f; Speed_PID.iMax = 1000.0f;
Speed_PID.iMin = -1000.0f; PID_Init(&Speed_PID);
// Bắt đầu Timer ngắt chu kỳ 10ms (100Hz) HAL_TIM_Base_Start_IT(&htim4);
// Kích hoạt ngắt nhận UART1 (1 byte) HAL_UART_Receive_IT(&huart1, (uint8_t*)&rxChar, 1); data = 0x00;
HAL_I2C_Mem_Write(&hi2c1,MPU6050_ADDR, 0x6B, I2C_MEMADD_SIZE_8BIT, &data, 1, HAL_MAX_DELAY);

MPU6050_GyroCalibration(); /* USER CODE END 2 */
/* Infinite loop */
/* USER CODE BEGIN WHILE */ while (1)
{
/* USER CODE END WHILE */
/* USER CODE BEGIN 3 */
// 1. Xử lý lệnh từ UART / Bluetooth if (cmdReady)
{
cmdReady = 0;
Process_Command();
}
// 2. Xuất dữ liệu Monitor / Plotter ngoài luồng ngắt (chu kỳ 100ms)

Process_Print();

HAL_Delay(100);
mpuStatus = HAL_I2C_IsDeviceReady(&hi2c1, MPU6050_ADDR, 3, 100); /*
if(mpuStatus == HAL_OK)
{
sprintf((char*)txBuf, "MPU6050 Found!\r\n"); }
else
{
sprintf((char*)txBuf, "MPU6050 Not Found!\r\n"); }
HAL_UART_Transmit(&huart1, txBuf, strlen((char*)txBuf), HAL_MAX_DELAY);
*/

HAL_I2C_Mem_Read(&hi2c1,MPU6050_ADDR,0x75,I2C_MEMADD_SIZE_8BIT, &who_am_i,1,HAL_MAX_DELAY); /*
sprintf((char*)txBuf, "WHO_AM_I = 0x%02X\r\n", who_am_i); HAL_UART_Transmit(&huart1,txBuf,strlen((char*)txBuf),HAL_MAX_DELAY); */

HAL_I2C_Mem_Read(&hi2c1, MPU6050_ADDR, 0x6B, I2C_MEMADD_SIZE_8BIT,

&data, 1, HAL_MAX_DELAY);

/*
sprintf((char*)txBuf, "PWR_MGMT_1 = 0x%02X\r\n", data); HAL_UART_Transmit(&huart1, txBuf, strlen((char*)txBuf), HAL_MAX_DELAY);

*/
HAL_I2C_Mem_Read(&hi2c1, MPU6050_ADDR, 0x3B, I2C_MEMADD_SIZE_8BIT, mpuData, 14, HAL_MAX_DELAY);
AccX = (int16_t)(mpuData[0] << 8 | mpuData[1]);
AccY = (int16_t)(mpuData[2] << 8 | mpuData[3]);
AccZ = (int16_t)(mpuData[4] << 8 | mpuData[5]);
Temp = (int16_t)(mpuData[6] << 8 | mpuData[7]);
GyroX = (int16_t)(mpuData[8] << 8 | mpuData[9]);
GyroY = (int16_t)(mpuData[10] << 8 | mpuData[11]);
GyroZ = (int16_t)(mpuData[12] << 8 | mpuData[13]);
Ax = (float)AccX / 16384.0f;
Ay = (float)AccY / 16384.0f;
Az = (float)AccZ / 16384.0f;
Gx = (float)GyroX / 131.0f - GxOffset;
Gy = (float)GyroY / 131.0f;
Gz = (float)GyroZ / 131.0f;
PitchAcc = atan2f(Ax,sqrtf(Ay*Ay + Az*Az))*180.0f/M_PI; RollAcc = atan2f(Ay, Az) * 180.0f / M_PI;
RollGyro = Roll + Gx * DT;

/* Complementary Filter */
Roll = 0.98f * RollGyro + 0.02f * RollAcc;
/*sprintf((char*)txBuf, "PitchAcc = %.2f | RollAcc = %.2f | Roll = %.2f\r\n", PitchAcc,RollAcc,Roll);*/

sprintf((char*)txBuf, "RollAcc=%.2f Gx=%.2f Roll=%.2f\r\n", RollAcc, Gx, Roll);

HAL_UART_Transmit(&huart1, txBuf, strlen((char *)txBuf), HAL_MAX_DELAY);

}
/* USER CODE END 3 */
}
/**
* @brief System Clock Configuration * @retval None
*/
void SystemClock_Config(void)
{
RCC_OscInitTypeDef RCC_OscInitStruct = {0};
RCC_ClkInitTypeDef RCC_ClkInitStruct = {0};
/** Initializes the RCC Oscillators according to the specified parameters * in the RCC_OscInitTypeDef structure. */
RCC_OscInitStruct.OscillatorType = RCC_OSCILLATORTYPE_HSE; RCC_OscInitStruct.HSEState = RCC_HSE_ON; RCC_OscInitStruct.HSEPredivValue = RCC_HSE_PREDIV_DIV1; RCC_OscInitStruct.HSIState = RCC_HSI_ON;

RCC_OscInitStruct.PLL.PLLState = RCC_PLL_ON; RCC_OscInitStruct.PLL.PLLSource = RCC_PLLSOURCE_HSE; RCC_OscInitStruct.PLL.PLLMUL = RCC_PLL_MUL9;
if (HAL_RCC_OscConfig(&RCC_OscInitStruct) != HAL_OK) {
Error_Handler();
}
/** Initializes the CPU, AHB and APB buses clocks
*/
RCC_ClkInitStruct.ClockType = RCC_CLOCKTYPE_HCLK|RCC_CLOCKTYPE_SYSCLK |RCC_CLOCKTYPE_PCLK1|RCC_CLOCKTYPE_PCLK2; RCC_ClkInitStruct.SYSCLKSource = RCC_SYSCLKSOURCE_PLLCLK; RCC_ClkInitStruct.AHBCLKDivider = RCC_SYSCLK_DIV1; RCC_ClkInitStruct.APB1CLKDivider = RCC_HCLK_DIV2; RCC_ClkInitStruct.APB2CLKDivider = RCC_HCLK_DIV1;
if (HAL_RCC_ClockConfig(&RCC_ClkInitStruct, FLASH_LATENCY_2) != HAL_OK) {
Error_Handler();
}
}
/**
* @brief I2C1 Initialization Function * @param None
* @retval None
*/
static void MX_I2C1_Init(void)
{
/* USER CODE BEGIN I2C1_Init 0 */ /* USER CODE END I2C1_Init 0 */ /* USER CODE BEGIN I2C1_Init 1 */ /* USER CODE END I2C1_Init 1 */ hi2c1.Instance = I2C1;
hi2c1.Init.ClockSpeed = 100000;

hi2c1.Init.DutyCycle = I2C_DUTYCYCLE_2; hi2c1.Init.OwnAddress1 = 0;
hi2c1.Init.AddressingMode = I2C_ADDRESSINGMODE_7BIT; hi2c1.Init.DualAddressMode = I2C_DUALADDRESS_DISABLE; hi2c1.Init.OwnAddress2 = 0;
hi2c1.Init.GeneralCallMode = I2C_GENERALCALL_DISABLE; hi2c1.Init.NoStretchMode = I2C_NOSTRETCH_DISABLE;
if (HAL_I2C_Init(&hi2c1) != HAL_OK)
{
Error_Handler();
}
/* USER CODE BEGIN I2C1_Init 2 */ /* USER CODE END I2C1_Init 2 */
}
/**
* @brief TIM2 Initialization Function * @param None
* @retval None
*/
static void MX_TIM2_Init(void)
{
/* USER CODE BEGIN TIM2_Init 0 */
/* USER CODE END TIM2_Init 0 */ TIM_ClockConfigTypeDef sClockSourceConfig = {0}; TIM_MasterConfigTypeDef sMasterConfig = {0}; TIM_OC_InitTypeDef sConfigOC = {0};
/* USER CODE BEGIN TIM2_Init 1 */
/* USER CODE END TIM2_Init 1 */
htim2.Instance = TIM2;
htim2.Init.Prescaler = 0;
htim2.Init.CounterMode = TIM_COUNTERMODE_UP; htim2.Init.Period = 3599;

htim2.Init.ClockDivision = TIM_CLOCKDIVISION_DIV1; htim2.Init.AutoReloadPreload = TIM_AUTORELOAD_PRELOAD_ENABLE; if (HAL_TIM_Base_Init(&htim2) != HAL_OK)
{
Error_Handler();
}
sClockSourceConfig.ClockSource = TIM_CLOCKSOURCE_INTERNAL;
if (HAL_TIM_ConfigClockSource(&htim2, &sClockSourceConfig) != HAL_OK) {
Error_Handler();
}
if (HAL_TIM_PWM_Init(&htim2) != HAL_OK) {
Error_Handler();
}
sMasterConfig.MasterOutputTrigger = TIM_TRGO_RESET; sMasterConfig.MasterSlaveMode = TIM_MASTERSLAVEMODE_DISABLE; if (HAL_TIMEx_MasterConfigSynchronization(&htim2, &sMasterConfig) != HAL_OK) {
Error_Handler();
}
sConfigOC.OCMode = TIM_OCMODE_PWM1; sConfigOC.Pulse = 0;
sConfigOC.OCPolarity = TIM_OCPOLARITY_HIGH;
sConfigOC.OCFastMode = TIM_OCFAST_DISABLE;
if (HAL_TIM_PWM_ConfigChannel(&htim2, &sConfigOC, TIM_CHANNEL_1) != HAL_OK) {
Error_Handler();
}
if (HAL_TIM_PWM_ConfigChannel(&htim2, &sConfigOC, TIM_CHANNEL_2) != HAL_OK) {
Error_Handler();
}
/* USER CODE BEGIN TIM2_Init 2 */ /* USER CODE END TIM2_Init 2 */ HAL_TIM_MspPostInit(&htim2);

}
/**
* @brief TIM3 Initialization Function * @param None
* @retval None
*/
static void MX_TIM3_Init(void)
{
/* USER CODE BEGIN TIM3_Init 0 */
/* USER CODE END TIM3_Init 0 */ TIM_Encoder_InitTypeDef sConfig = {0}; TIM_MasterConfigTypeDef sMasterConfig = {0}; /* USER CODE BEGIN TIM3_Init 1 */
/* USER CODE END TIM3_Init 1 */
htim3.Instance = TIM3;
htim3.Init.Prescaler = 0;
htim3.Init.CounterMode = TIM_COUNTERMODE_UP; htim3.Init.Period = 65535;
htim3.Init.ClockDivision = TIM_CLOCKDIVISION_DIV1; htim3.Init.AutoReloadPreload = TIM_AUTORELOAD_PRELOAD_DISABLE; sConfig.EncoderMode = TIM_ENCODERMODE_TI12; sConfig.IC1Polarity = TIM_ICPOLARITY_RISING;
sConfig.IC1Selection = TIM_ICSELECTION_DIRECTTI; sConfig.IC1Prescaler = TIM_ICPSC_DIV1; sConfig.IC1Filter = 10;
sConfig.IC2Polarity = TIM_ICPOLARITY_RISING; sConfig.IC2Selection = TIM_ICSELECTION_DIRECTTI; sConfig.IC2Prescaler = TIM_ICPSC_DIV1; sConfig.IC2Filter = 10;
if (HAL_TIM_Encoder_Init(&htim3, &sConfig) != HAL_OK) {
Error_Handler();
}

sMasterConfig.MasterOutputTrigger = TIM_TRGO_RESET; sMasterConfig.MasterSlaveMode = TIM_MASTERSLAVEMODE_DISABLE; if (HAL_TIMEx_MasterConfigSynchronization(&htim3, &sMasterConfig) != HAL_OK) {
Error_Handler();
}
/* USER CODE BEGIN TIM3_Init 2 */ /* USER CODE END TIM3_Init 2 */ }
/**
* @brief TIM4 Initialization Function * @param None
* @retval None
*/
static void MX_TIM4_Init(void)
{
/* USER CODE BEGIN TIM4_Init 0 */
/* USER CODE END TIM4_Init 0 */ TIM_ClockConfigTypeDef sClockSourceConfig = {0}; TIM_MasterConfigTypeDef sMasterConfig = {0}; /* USER CODE BEGIN TIM4_Init 1 */
/* USER CODE END TIM4_Init 1 */
htim4.Instance = TIM4;
htim4.Init.Prescaler = 7199;
htim4.Init.CounterMode = TIM_COUNTERMODE_UP; htim4.Init.Period = 99;
htim4.Init.ClockDivision = TIM_CLOCKDIVISION_DIV1; htim4.Init.AutoReloadPreload = TIM_AUTORELOAD_PRELOAD_DISABLE; if (HAL_TIM_Base_Init(&htim4) != HAL_OK)
{
Error_Handler();

}
sClockSourceConfig.ClockSource = TIM_CLOCKSOURCE_INTERNAL;
if (HAL_TIM_ConfigClockSource(&htim4, &sClockSourceConfig) != HAL_OK) {
Error_Handler();
}
sMasterConfig.MasterOutputTrigger = TIM_TRGO_RESET; sMasterConfig.MasterSlaveMode = TIM_MASTERSLAVEMODE_DISABLE; if (HAL_TIMEx_MasterConfigSynchronization(&htim4, &sMasterConfig) != HAL_OK) {
Error_Handler();
}
/* USER CODE BEGIN TIM4_Init 2 */ /* USER CODE END TIM4_Init 2 */
}
/**
* @brief USART1 Initialization Function * @param None
* @retval None
*/
static void MX_USART1_UART_Init(void) {
/* USER CODE BEGIN USART1_Init 0 */ /* USER CODE END USART1_Init 0 */ /* USER CODE BEGIN USART1_Init 1 */ /* USER CODE END USART1_Init 1 */ huart1.Instance = USART1;
huart1.Init.BaudRate = 115200; huart1.Init.WordLength = UART_WORDLENGTH_8B; huart1.Init.StopBits = UART_STOPBITS_1; huart1.Init.Parity = UART_PARITY_NONE; huart1.Init.Mode = UART_MODE_TX_RX;

huart1.Init.HwFlowCtl = UART_HWCONTROL_NONE; huart1.Init.OverSampling = UART_OVERSAMPLING_16; if (HAL_UART_Init(&huart1) != HAL_OK)
{
Error_Handler();
}
/* USER CODE BEGIN USART1_Init 2 */ /* USER CODE END USART1_Init 2 */ }
/**
* @brief GPIO Initialization Function * @param None
* @retval None
*/
static void MX_GPIO_Init(void)
{
GPIO_InitTypeDef GPIO_InitStruct = {0}; /* USER CODE BEGIN MX_GPIO_Init_1 */ /* USER CODE END MX_GPIO_Init_1 */ /* GPIO Ports Clock Enable */
__HAL_RCC_GPIOD_CLK_ENABLE(); __HAL_RCC_GPIOA_CLK_ENABLE(); __HAL_RCC_GPIOB_CLK_ENABLE();

/*Configure GPIO pin Output Level */
HAL_GPIO_WritePin(GPIOA, GPIO_PIN_2|GPIO_PIN_3|GPIO_PIN_4|GPIO_PIN_5 |GPIO_PIN_6, GPIO_PIN_RESET); /*Configure GPIO pins : PA2 PA3 PA4 PA5
PA6 */
GPIO_InitStruct.Pin = GPIO_PIN_2|GPIO_PIN_3|GPIO_PIN_4|GPIO_PIN_5 |GPIO_PIN_6;
GPIO_InitStruct.Mode = GPIO_MODE_OUTPUT_PP; GPIO_InitStruct.Pull = GPIO_NOPULL;
GPIO_InitStruct.Speed = GPIO_SPEED_FREQ_LOW;

HAL_GPIO_Init(GPIOA, &GPIO_InitStruct); /* USER CODE BEGIN MX_GPIO_Init_2 */ /* USER CODE END MX_GPIO_Init_2 */
}
/* USER CODE BEGIN 4 */
void Motor_SetPWM(int pwm)
{
if(pwm > 3599) pwm = 3599; if(pwm < -3599) pwm = -3599;
if(pwm >= 0)
{
HAL_GPIO_WritePin(GPIOA, GPIO_PIN_5, GPIO_PIN_SET); HAL_GPIO_WritePin(GPIOA, GPIO_PIN_6, GPIO_PIN_RESET); __HAL_TIM_SET_COMPARE(&htim2, TIM_CHANNEL_2, pwm); }
else
{
HAL_GPIO_WritePin(GPIOA, GPIO_PIN_5, GPIO_PIN_RESET); HAL_GPIO_WritePin(GPIOA, GPIO_PIN_6, GPIO_PIN_SET); __HAL_TIM_SET_COMPARE(&htim2, TIM_CHANNEL_2, -pwm); }
}
void Encoder_Update(void)
{
encoder_now = (int16_t)__HAL_TIM_GET_COUNTER(&htim3); encoder_delta = encoder_now - encoder_old;
encoder_old = encoder_now;
encoder_position += encoder_delta;
encoder_rpm = (float)encoder_delta * RPM_FACTOR; }
void Control_Loop(void)
{

Encoder_Update();
if (control_mode == MODE_PID_SPEED) {
Speed_PID.feedback = encoder_rpm; Speed_PID.setpoint = target_rpm; float out = PID_Update(&Speed_PID); Motor_SetPWM((int)out);
}
else
{
Motor_SetPWM(manual_pwm);
}
}
void HAL_TIM_PeriodElapsedCallback(TIM_HandleTypeDef *htim) {
if(htim->Instance == TIM4)
{
timer_cnt++;
Control_Loop(); // Tính toán PID mỗi 10ms
// Bật cờ xuất dữ liệu UART sau mỗi 100ms (10 x 10ms) static uint8_t print_cnt = 0;
if (++print_cnt >= 10)
{
print_cnt = 0;
if (print_mode != PRINT_OFF) {
print_flag = 1;
}
}
}
}
void PID_Init(PID_t *pid)
{
pid->error = 0.0f;
pid->last_error = 0.0f;
pid->integral = 0.0f;

pid->derivative = 0.0f;
pid->P_term = 0.0f;
pid->I_term = 0.0f;
pid->D_term = 0.0f;
pid->output = 0.0f;
pid->setpoint = 0.0f;
pid->feedback = 0.0f;
}
float PID_Update(PID_t *pid)
{
pid->error = pid->setpoint - pid->feedback;
// Tích phân (Integral)
pid->integral += pid->error * pid->Ts;
if(pid->integral > pid->iMax) pid->integral = pid->iMax; if(pid->integral < pid->iMin) pid->integral = pid->iMin; // Vi phân (Derivative)
pid->derivative = (pid->error - pid->last_error) / pid->Ts; // Tính riêng từng thành phần
pid->P_term = pid->Kp * pid->error;
pid->I_term = pid->Ki * pid->integral;
pid->D_term = pid->Kd * pid->derivative;
// Tổng ngõ ra
pid->output = pid->P_term + pid->I_term + pid->D_term; // Bão hòa ngõ ra PWM
if(pid->output > pid->outMax) pid->output = pid->outMax; if(pid->output < pid->outMin) pid->output = pid->outMin; pid->last_error = pid->error;
return pid->output;
}

/*======================================================= =============
* UART MONITOR / PLOTTER PRINT PROCESSOR (Chạy trong vòng lặp while(1)) *======================================================= ============= */
void Process_Print(void)
{
if (!print_flag) return;
print_flag = 0; // Reset cờ
char msg[160];
if (print_mode == PRINT_MONITOR)
{
// Hiển thị cả Kp Ki Kd | Target, Real, Err | P, I, D | Output PWM
sprintf(msg, "[Kp:%.1f Ki:%.1f Kd:%.1f] | T:%5.1f R:%5.1f E:%5.1f | P:%6.1f
I:%6.1f D:%6.1f | OUT:%5.0f\r\n", Speed_PID.Kp, Speed_PID.Ki, Speed_PID.Kd, target_rpm, encoder_rpm, Speed_PID.error, Speed_PID.P_term, Speed_PID.I_term, Speed_PID.D_term, Speed_PID.output);

HAL_UART_Transmit(&huart1, (uint8_t*)msg, strlen(msg), 30); }
else if (print_mode == PRINT_PLOT)
{
// Định dạng CSV dành cho Serial Plotter vẽ 5 đường đồng thời: // Cú pháp: Target, RPM, P_term, I_term, D_term
sprintf(msg, "%.1f,%.1f,%.1f,%.1f,%.1f\r\n", target_rpm, encoder_rpm, Speed_PID.P_term, Speed_PID.I_term, Speed_PID.D_term);

HAL_UART_Transmit(&huart1, (uint8_t*)msg, strlen(msg), 20); }
}

/*======================================================= =============
* CLI COMMAND PROCESSOR
*======================================================= ============= */
void Process_Command(void)
{
char msg[128];
// --- Lệnh HELP ---
if(strcmp(rxBuffer, "HELP") == 0)
{
char *help_text =
"\r\n========== COMMAND LIST ==========\r\n" "HELP : Show command menu\r\n"
"PWM xxx : Set manual PWM (-3599 to 3599)\r\n" "RPM xxx : Set target RPM (Enable PID)\r\n"
"STOP : Stop motor & reset mode\r\n"
"STATUS : Show Mode, RPM & Encoder\r\n"
"MONITOR : Stream Kp,Ki,Kd | T,R,E | P,I,D | OUT\r\n"
"PLOT : Stream CSV (Target,RPM,P,I,D) for Plotter\r\n" "STOPMON : Stop streaming data\r\n"
"ENC : Show Encoder position\r\n"
"KP xxx : Set Speed PID Kp\r\n"
"KI xxx : Set Speed PID Ki\r\n"
"KD xxx : Set Speed PID Kd\r\n" "==================================\r\n"; HAL_UART_Transmit(&huart1, (uint8_t*)help_text, strlen(help_text), 100); }
// --- Lệnh PWM xxx --- else if(strncmp(rxBuffer, "PWM ", 4) == 0)
{
int val = 0;
if(sscanf(rxBuffer + 4, "%d", &val) == 1) {
control_mode = MODE_MANUAL_PWM; manual_pwm = val;

Motor_SetPWM(manual_pwm);
sprintf(msg, "\r\n[MODE] Manual PWM = %d\r\n", manual_pwm); HAL_UART_Transmit(&huart1, (uint8_t*)msg, strlen(msg), 100);
}
}
// --- Lệnh RPM xxx --- else if(strncmp(rxBuffer, "RPM ", 4) == 0)
{
float val = 0.0f;
if(sscanf(rxBuffer + 4, "%f", &val) == 1) {
control_mode = MODE_PID_SPEED;
target_rpm = val;
sprintf(msg, "\r\n[MODE] PID Speed Target = %.2f RPM\r\n", target_rpm); HAL_UART_Transmit(&huart1, (uint8_t*)msg, strlen(msg), 100);
}
}
// --- Lệnh MONITOR --- else if(strcmp(rxBuffer, "MONITOR") == 0)
{
print_mode = PRINT_MONITOR;
char *m = "\r\n[MONITOR ON - Full PID Inspection]\r\n"; HAL_UART_Transmit(&huart1, (uint8_t*)m, strlen(m), 50); }
// --- Lệnh PLOT --- else if(strcmp(rxBuffer, "PLOT") == 0)
{
print_mode = PRINT_PLOT;
}
// --- Lệnh STOPMON --- else if(strcmp(rxBuffer, "STOPMON") == 0) {
print_mode = PRINT_OFF;
char *m = "\r\n[MONITOR OFF]\r\n"; HAL_UART_Transmit(&huart1, (uint8_t*)m, strlen(m), 50); }
// --- Lệnh STOP --- else if(strcmp(rxBuffer, "STOP") == 0)

{
control_mode = MODE_MANUAL_PWM; manual_pwm = 0;
target_rpm = 0.0f;
Motor_SetPWM(0);
sprintf(msg, "\r\nMotor Stopped!\r\n"); HAL_UART_Transmit(&huart1, (uint8_t*)msg, strlen(msg), 100); }
// --- Lệnh STATUS --- else if(strcmp(rxBuffer, "STATUS") == 0)
{
sprintf(msg, "\r\nMode: %s | PWM: %d | Target RPM: %.1f | Current
RPM: %.1f | Pos: %ld\r\n", (control_mode == MODE_PID_SPEED) ? "PID_SPEED" : "MANUAL_PWM", manual_pwm, target_rpm, encoder_rpm, (long)encoder_position);

HAL_UART_Transmit(&huart1, (uint8_t*)msg, strlen(msg), 100);
}
// --- Lệnh ENC --- else if(strcmp(rxBuffer, "ENC") == 0 || strcmp(rxBuffer, "POS") == 0)
{
sprintf(msg, "\r\nEncoder Pos = %ld\r\n", (long)encoder_position); HAL_UART_Transmit(&huart1, (uint8_t*)msg, strlen(msg), 100);
}
// --- Lệnh chỉnh PID Kp --- else if(strncmp(rxBuffer, "KP ", 3) == 0)
{
float val = 0.0f;
if(sscanf(rxBuffer + 3, "%f", &val) == 1)
{
Speed_PID.Kp = val;
sprintf(msg, "\r\nKp set to %.3f\r\n", Speed_PID.Kp); HAL_UART_Transmit(&huart1, (uint8_t*)msg, strlen(msg), 100); }
}
// --- Lệnh chỉnh PID Ki --- else if(strncmp(rxBuffer, "KI ", 3) == 0)
{
float val = 0.0f;
if(sscanf(rxBuffer + 3, "%f", &val) == 1)

{
Speed_PID.Ki = val;
sprintf(msg, "\r\nKi set to %.3f\r\n", Speed_PID.Ki); HAL_UART_Transmit(&huart1, (uint8_t*)msg, strlen(msg), 100); }
}
// --- Lệnh chỉnh PID Kd --- else if(strncmp(rxBuffer, "KD ", 3) == 0)
{
float val = 0.0f;
if(sscanf(rxBuffer + 3, "%f", &val) == 1)
{
Speed_PID.Kd = val;
sprintf(msg, "\r\nKd set to %.3f\r\n", Speed_PID.Kd); HAL_UART_Transmit(&huart1, (uint8_t*)msg, strlen(msg), 100); }
}
// --- Lệnh không xác định --- else
{
sprintf(msg, "\r\nUnknown Command: %s\r\n", rxBuffer); HAL_UART_Transmit(&huart1, (uint8_t*)msg, strlen(msg), 100);
}
}
/*======================================================= =============
* UART CLI RECEIVER & CALLBACKS *======================================================= ============= */
void HAL_UART_RxCpltCallback(UART_HandleTypeDef *huart)
{
if(huart->Instance == USART1)
{
// 1. Echo ký tự vừa gõ
HAL_UART_Transmit(&huart1, (uint8_t*)&rxChar, 1, 10); // 2. Kiểm tra ký tự kết thúc dòng if (rxChar == '\r' || rxChar == '\n') {
if (rxIndex > 0)
{
rxBuffer[rxIndex] = '\0';
cmdReady = 1;
rxIndex = 0;
}
}
else
{
if (rxIndex < (sizeof(rxBuffer) - 1)) {
rxBuffer[rxIndex++] = rxChar; }
else
{
rxIndex = 0; // Chống tràn bộ đệm }
}
// 3. Tiếp tục lắng nghe ký tự tiếp theo HAL_UART_Receive_IT(&huart1, (uint8_t*)&rxChar, 1); }
}
void HAL_UART_ErrorCallback(UART_HandleTypeDef *huart) {
if(huart->Instance == USART1)
{ __HAL_UART_CLEAR_OREFLAG(huart); __HAL_UART_CLEAR_NEFLAG(huart); __HAL_UART_CLEAR_FEFLAG(huart);

HAL_UART_Receive_IT(&huart1, (uint8_t*)&rxChar, 1); }
}
void MPU6050_GyroCalibration(void)
{

float sum = 0.0f;
for(int i = 0; i < 1000; i++)
{
HAL_I2C_Mem_Read(&hi2c1, MPU6050_ADDR, 0x43, I2C_MEMADD_SIZE_8BIT, &mpuData[8], 6, HAL_MAX_DELAY);
GyroX = (int16_t)(mpuData[8] << 8 | mpuData[9]);
Gx = (float)GyroX / 131.0f;
sum += Gx;
HAL_Delay(2);
}
GxOffset = sum / 1000.0f;

sprintf((char*)txBuf, "Gyro X Offset = %.3f\r\n", GxOffset);

HAL_UART_Transmit(&huart1, txBuf, strlen((char*)txBuf), HAL_MAX_DELAY);

}

/* USER CODE END 4 */
/**

* @brief This function is executed in case of error occurrence. * @retval None */
void Error_Handler(void)
{
/* USER CODE BEGIN Error_Handler_Debug */ __disable_irq();
while (1)
{
}
/* USER CODE END Error_Handler_Debug */ }
#ifdef USE_FULL_ASSERT

/**
* @brief Reports the name of the source file and the source line number * where the assert_param error has occurred. * @param file: pointer to the source file name
* @param line: assert_param error line source number
* @retval None
*/
void assert_failed(uint8_t *file, uint32_t line)
{
/* USER CODE BEGIN 6 */
/* USER CODE END 6 */
}
#endif /* USE_FULL_ASSERT */

### 1. Nguyên nhân gây ra Drift & Lỗi trong Code

Lỗi 1: Sai số Thời gian lấy mẫu DT (Nguyên nhân lớn nhất làm Roll tăng/giảm dần)• Thực tế trong code: Trong main.c, bạn đang định nghĩa #define DT 0.1f
| (tương đương 100ms) và bạn tính bộ lọc trong hàm while(1) có chứa HAL_Delay(100). • Vấn đề:

### 1. HAL_Delay(100) cộng với thời gian đọc I2C và truyền UART khiến chu

| kỳ thực tế bị lệch (ví dụ thành 105ms – 110ms) chứ không tròn 100ms. 2. Chu kỳ lấy mẫu góc 100ms (10Hz) là quá chậm cho robot tự cân bằng. Robot 2 bánh cần vòng lặp lấy mẫu góc ít nhất 100Hz (10ms).

### 3. Lỗi tích phân Gyro G × D sẽ tích lũy sai số rất nhanh nếu D bị lệch

với chu kỳ thực tế. Lỗi 2: Hàm Calibration Gyro chạy quá sớm khi MPU6050 chưa ổn định
- Vấn đề: Trong main(), ngay sau khi ghi thanh ghi 0x6B = 0 (Wake up MPU), bạn gọi ngay hàm MPU6050_GyroCalibration(). • Thực tế phần cứng: Khi vừa thoát khỏi chế độ Sleep, các cảm biến cơ khí

MEMS bên trong MPU6050 chưa ổn định điện áp và nhiệt độ. Calibration lúc này sẽ tính ra GxOffset sai lệch đáng kể. Lỗi 3: Chế độ Power Management 1 (Register 0x6B) chưa chọn Clock Source tốt
- Vấn đề: Bạn ghi 0x00 vào thanh ghi 0x6B. Giá trị 0x00 bắt MPU6050 dùng dao động nội 8MHz (Internal 8MHz oscillator). Dao động nội này rất dễ bị trôi theo nhiệt độ. • Khắc phục: MPU6050 khuyến cáo nên set thanh ghi 0x6B thành 0x01 để dùng PLL với trục Gyro X làm clock reference (ổn định hơn rất nhiều). 2. Giải đáp chi tiết các nghi vấn của bạn (Mục 10)
A. Về Calibration:

### 1. Có cần delay sau khi wake MPU6050 không?

- CÓ. Cần HAL_Delay(100) đến 200ms sau khi ghi thanh ghi 0x6B để cảm biến kịp định hình nguồn và dao động. 2. Calibration 1000 mẫu có đủ không?
- ĐỦ. 1000 mẫu với HAL_Delay(2) ngốn tầm 2 giây là đủ tốt. Tuy nhiên, robot phải nằm yên tuyệt đối trong thời gian này. 3. Có cần calibrate GyroY / GyroZ không?
- NÊN. Dù chỉ dùng Roll (G), nhưng việc tính sẵn Offset cho GyroY, GyroZ rất đơn giản và giúp bạn không bị bối rối nếu sau này dùng

đến. 4. Offset có bị sai do sensor chưa ổn định?
- ĐÚNG. Đây chính là nguyên nhân dẫn đến G sau khi trừ offset vẫn bị sót lại một lượng nhỏ (≈ . 0 − . 0

∘/). Tích phân theo thời gian sẽ

làm góc trôi từ từ. B. Về Drift: • Nếu G ≠ khi đứng yên: Là do Offset chưa chuẩn. • Nếu G ≈ mà Roll vẫn tăng/giảm dần: Là do Bộ lọc Complementary chưa

hoạt động đúng để kéo Roll về Rl, hoặc D bị tính sai số. 3. Giải pháp khắc phục triệt để

Chúng ta sẽ chuyển toàn bộ quá trình đọc MPU6050 + tính Complementary Filter vào trong ngắt TIM4 (100Hz / 10ms) chung với vòng lặp điều khiển, loại bỏ việc đọc cảm biến trong while(1). Bước 1: Sửa lại Macro DT và Khởi tạo MPU
Thay đổi trong #define:

C
/* USER CODE BEGIN PD */
#define ENCODER_CPR 1320.0f

#define SAMPLE_TIME 0.01f

#define RPM_FACTOR (60.0f / (ENCODER_CPR * SAMPLE_TIME))

#define MPU6050_ADDR (0x68 << 1)

#define M_PI 3.14159265358979323846

#define DT 0.01f // SỬA: DT = 10ms (100Hz) để khớp chính xác với ngắt TIM4 /* USER CODE END PD */

Bước 2: Nâng cấp hàm Calibration Gyro (có delay khởi động)
Sửa hàm MPU6050_GyroCalibration() trong main.c:
C
void MPU6050_GyroCalibration(void)
{
float sum = 0.0f;
// Đảm bảo robot nằm yên trong lúc này! for(int i = 0; i < 1000; i++)
{
HAL_I2C_Mem_Read(&hi2c1, MPU6050_ADDR, 0x43, I2C_MEMADD_SIZE_8BIT, &mpuData[8], 2, // Chỉ cần đọc 2 byte GyroX

HAL_MAX_DELAY);
int16_t raw_gx = (int16_t)(mpuData[8] << 8 | mpuData[9]);
sum += ((float)raw_gx / 131.0f);
HAL_Delay(2);
}
GxOffset = sum / 1000.0f;
sprintf((char*)txBuf, "Gyro X Offset Calibrated: %.3f deg/s\r\n", GxOffset); HAL_UART_Transmit(&huart1, txBuf, strlen((char*)txBuf), HAL_MAX_DELAY);
}
Bước 3: Đưa việc tính Góc Roll vào Control_Loop() (Chạy chuẩn 100Hz trong TIM4)

Tạo hàm đọc và cập nhật góc MPU6050: C
void MPU6050_Read_Angle(void)
{
// Đọc 14 bytes dữ liệu
if(HAL_I2C_Mem_Read(&hi2c1, MPU6050_ADDR, 0x3B, I2C_MEMADD_SIZE_8BIT, mpuData, 14, 10) == HAL_OK) {
AccY = (int16_t)(mpuData[2] << 8 | mpuData[3]);
AccZ = (int16_t)(mpuData[4] << 8 | mpuData[5]);
GyroX = (int16_t)(mpuData[8] << 8 | mpuData[9]);
Ay = (float)AccY / 16384.0f;
Az = (float)AccZ / 16384.0f;
// Trừ offset chính xác
Gx = ((float)GyroX / 131.0f) - GxOffset;
// Tính góc Roll từ Gia tốc
RollAcc = atan2f(Ay, Az) * 180.0f / M_PI;
// Complementary Filter với DT chuẩn = 0.01s (10ms)
// Formula: Roll = alpha * (Roll + Gx * DT) + (1 - alpha) * RollAcc Roll = 0.98f * (Roll + Gx * DT) + 0.02f * RollAcc;
}
}
Cập nhật lại Control_Loop() trong ngắt TIM4:
C
void Control_Loop(void)
{
// 1. Đọc góc nghiêng ở tần số 100Hz MPU6050_Read_Angle();
// 2. Cập nhật Encoder
Encoder_Update();
// 3. Xử lý Chế độ điều khiển
if (control_mode == MODE_PID_SPEED) {
Speed_PID.feedback = encoder_rpm;

Speed_PID.setpoint = target_rpm; float out = PID_Update(&Speed_PID); Motor_SetPWM((int)out);
}
else
{
Motor_SetPWM(manual_pwm);
}
}
Bước 4: Sửa luồng khởi tạo trong main()
Trong hàm main(), sửa đoạn Wake up MPU và gọi Calibration: C
/* USER CODE BEGIN 2 */
// ... (Giữ nguyên phần PWM, Encoder, PID_Init, Timer4)
// Wake up MPU6050 & Chọn Clock Source = PLL GyroX (0x01)
data = 0x01;
HAL_I2C_Mem_Write(&hi2c1, MPU6050_ADDR, 0x6B, I2C_MEMADD_SIZE_8BIT, &data, 1, HAL_MAX_DELAY);

// Chờ MPU6050 ổn định điện áp và phần cơ MEMS
HAL_Delay(200);
// Calibration Gyro khi robot đứng yên
MPU6050_GyroCalibration();
// Khởi tạo giá trị ban đầu cho Roll bằng đúng RollAcc để tránh giật góc ban đầu HAL_I2C_Mem_Read(&hi2c1, MPU6050_ADDR, 0x3B, I2C_MEMADD_SIZE_8BIT, mpuData, 6, HAL_MAX_DELAY);
AccY = (int16_t)(mpuData[2] << 8 | mpuData[3]);
AccZ = (int16_t)(mpuData[4] << 8 | mpuData[5]);
Roll = atan2f((float)AccY / 16384.0f, (float)AccZ / 16384.0f) * 180.0f / M_PI; // Bắt đầu Timer ngắt chu kỳ 10ms (100Hz) HAL_TIM_Base_Start_IT(&htim4);
/* USER CODE END 2 */
Và làm sạch vòng lặp while(1) (loại bỏ việc đọc MPU trùng lặp trong while): C
/* USER CODE BEGIN WHILE */
while (1)

{
/* USER CODE END WHILE */
/* USER CODE BEGIN 3 */
if (cmdReady)
{
cmdReady = 0;
Process_Command();
}
// In dữ liệu UART ra ngoài màn hình MONITOR / PLOTTER Process_Print();
}
/* USER CODE END 3 */

### 4. Cách kiểm tra dữ liệu qua UART (Mục 11)

Sau khi nạp code đã cập nhật ở trên, hãy bật Terminal UART để quan sát chuỗi in ra:

### 1. Kiểm tra Gyro X Offset: Lúc khởi động, xem Terminal báo Gyro X Offset

Calibrated: .... Giá trị này thường nằm trong khoảng -3.0 đến +3.0 deg/s. 2. Kiểm tra khi Robot đặt cố định trên mặt phẳng:
- Gx phải dao động quanh . ± . 0

∘/. o RollAcc đứng yên một giá trị (ví dụ .
∘). o Roll phải ổn định tuyệt đối quanh giá trị của RollAcc, không được trôi

tăng/giảm theo thời gian. 3. Kiểm tra độ nhạy động: Nghiêng robot sang trái/phải rồi giữ nguyên ở góc mới, quan sát giá trị Roll xem có bám kịp theo RollAcc nhanh chóng và không bị đung đưa không. Thử nghiệm xong phần này, nếu góc Roll đã phẳng và ổn định, bạn đã sẵn sàng 100% để bước sang cài đặt Angle PID!

- Vấn đề nghiêm trọng, MPU driff - thử debug kiểu mới -> giải quyết vấn đề bị gián đoạn khi đang quay -> cân nhắc không sử dụng UART quá nhiều gây gián đoạn hoặc tìm một cách nào đó để giữ cho việc truyền tín hiệu trở nên đều đặn và có chu kì hơn

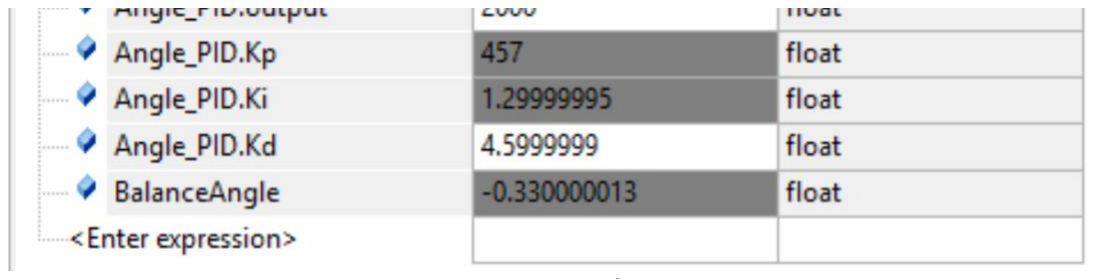
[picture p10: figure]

Thông số này cân bằng biên độ nhỏ ổn định vô thời hạn

Một số vấn đề cần cải thiện ở “Phần cứng”: - thiết kế sao cho có thể điều chỉnh được trọng tâm của robot - Độ tin cậy của một số chi tiết cần được đảm bao với tiêu chuẩn cao

+ khe đựng mạch có chưa MPU phải cố định, không được lung lay hoặc dễ bị điều chỉnh
+ độ rơ của động cơ
+ một số chi tiết hỗ trợ tunning cho robot: cái móc trên đầu…
+ bảo vệ mạch (các chân mạch nạp ở stm32 dễ bị gãy khi debug

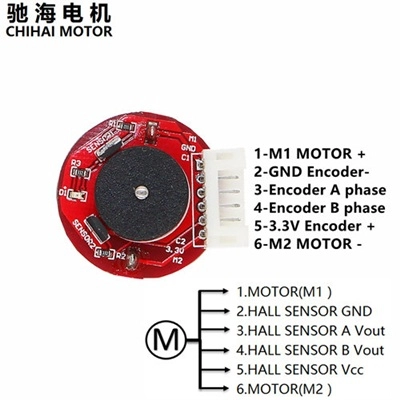
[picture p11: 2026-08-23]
docs/pinout/htb15w4csvxxxxcixpxxq6xxfxxxg-2d6d5d37-308e-4e10-a770-f7abc8fefdd3.jpg

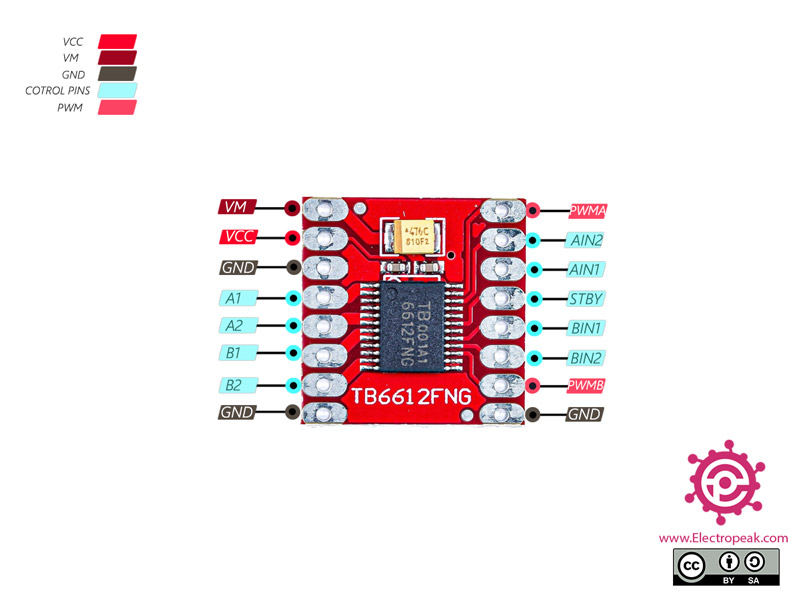
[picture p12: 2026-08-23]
docs/pinout/TB6612FBG-Dual-Driver-Pinout.jpg

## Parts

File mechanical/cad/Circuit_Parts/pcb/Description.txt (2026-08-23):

PCB Prototype Development Board, 6x8 cm

Link to CAD files:
https://grabcad.com/library/pcb-prototype-development-board-6x8-cm-1

Links to vendors:
https://www.amazon.com/Single-Sided-Universal-Packs-12x18/dp/B08WPYPST7
https://www.amazon.com/ELEGOO-Prototype-Soldering-Compatible-Arduino/dp/B072Z7Y19F

Type: Double Side Tinned Prototype Universal DIY PCB Board
Dimension: (WxLxT) 60x80x1.6mm, hole pitch 2.54mm, hole diameter 0.95mm.
Usage: Both of the two sides have pads with a hole in communication, and can be welded components.
Applications: For point to point DIY soldering, Be widely used in teaching experiments, product research and development, set up the DEMO board, etc.

#CAD #SolidWorks #3dmodeling #developmentboard #prototypeboard #pcbboard

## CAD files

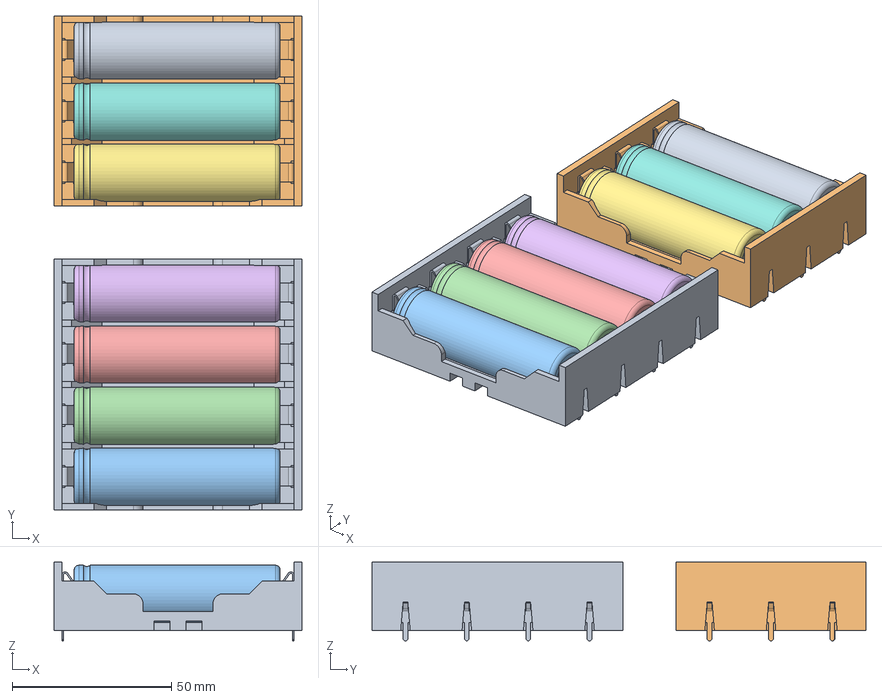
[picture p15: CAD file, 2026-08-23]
mechanical/cad/Circuit_Parts/battery/FreeCAD Files/Battery Holders Assembly.FCStd
78.0 x 155.2 x 24.7 mm
4 Battery Holder_001
3 Battery Holder_001
18650 Lipo Battery_001
18650 Lipo Battery_002
18650 Lipo Battery_003
18650 Lipo Battery_004
18650 Lipo Battery_005
18650 Lipo Battery_006
18650 Lipo Battery_007

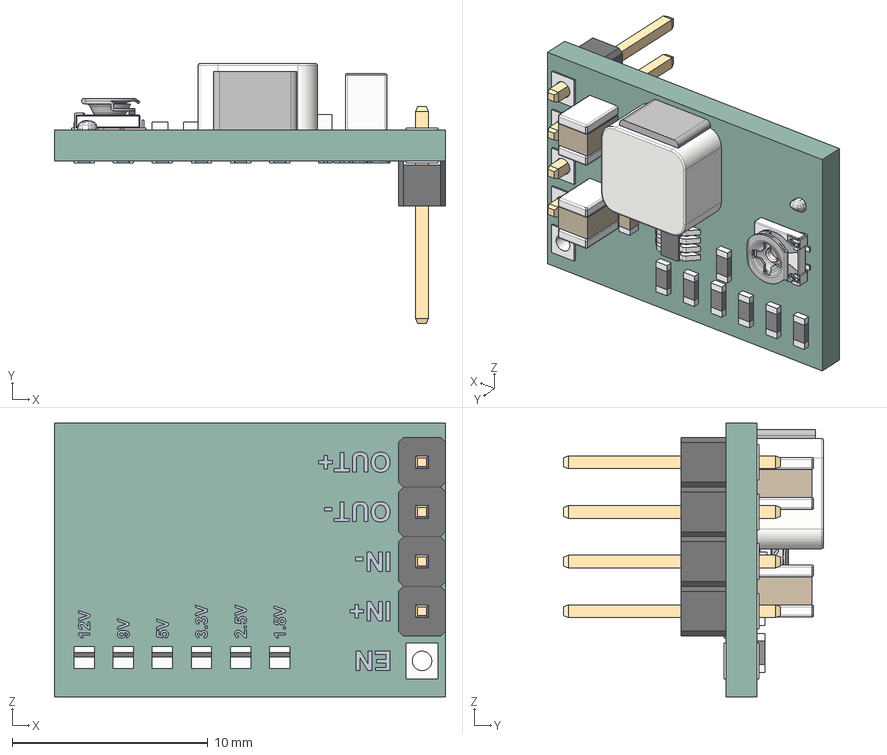
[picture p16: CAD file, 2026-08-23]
mechanical/cad/Circuit_Parts/bunk/dc_12v_to_5v_buck_converter_asm.stp
20.0 x 13.3 x 14.0 mm
BOARD
1X_M_PIN_2_54_MM x 4
LETTER

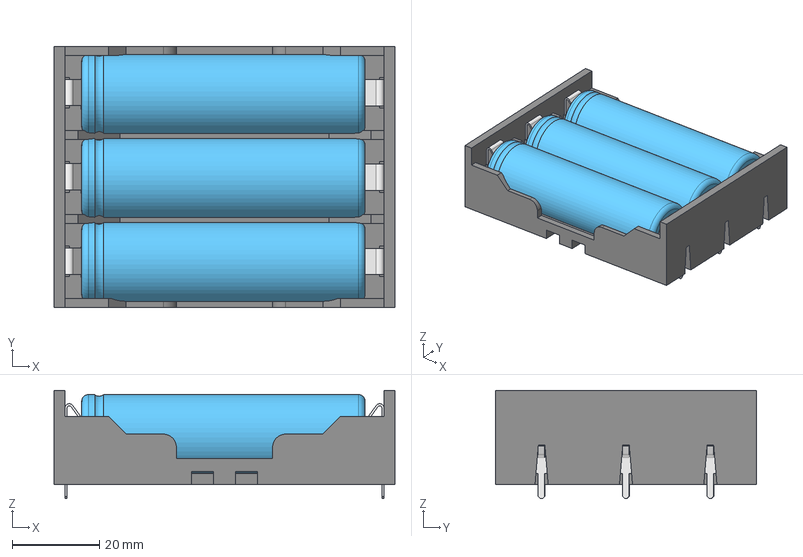
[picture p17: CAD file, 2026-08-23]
mechanical/cad/Circuit_Parts/battery/3 Battery Holder With Batteries.step
78.0 x 59.6 x 24.7 mm

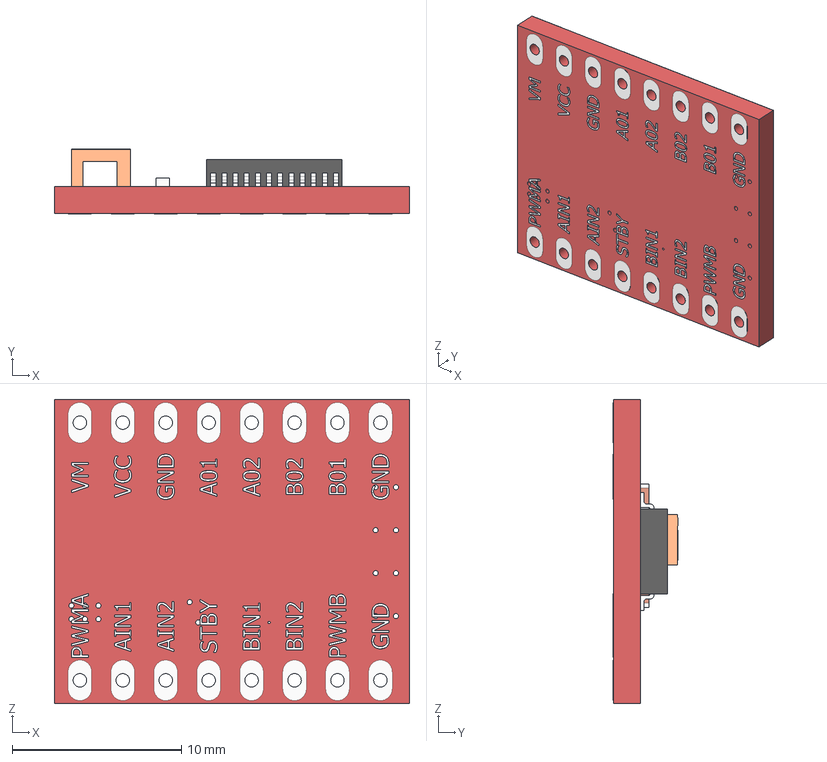
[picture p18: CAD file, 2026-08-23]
mechanical/cad/Circuit_Parts/dong co/TB6612FNG.stp
21.0 x 3.82 x 18.0 mm

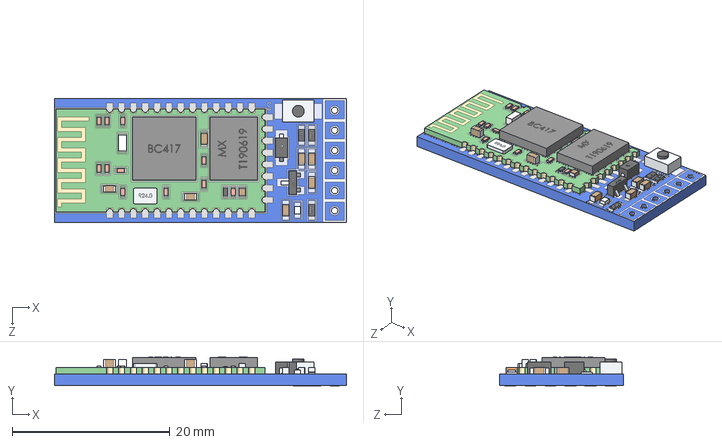
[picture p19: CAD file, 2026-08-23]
mechanical/cad/Circuit_Parts/hc05/HC05.STEP
37.0 x 3.62 x 15.7 mm

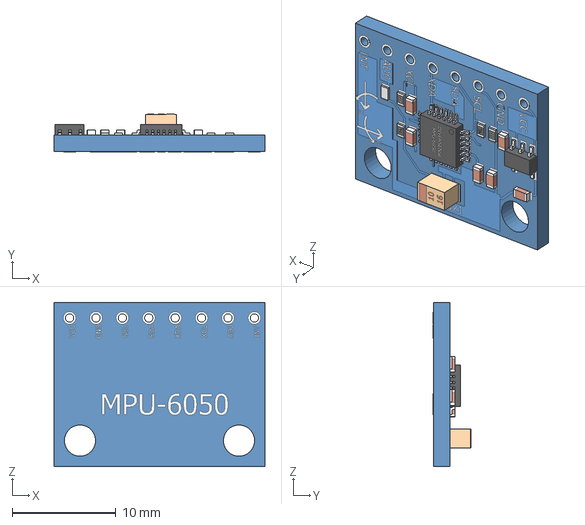
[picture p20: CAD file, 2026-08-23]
mechanical/cad/Circuit_Parts/mpu/MPU6050.stp
20.3 x 3.62 x 15.8 mm

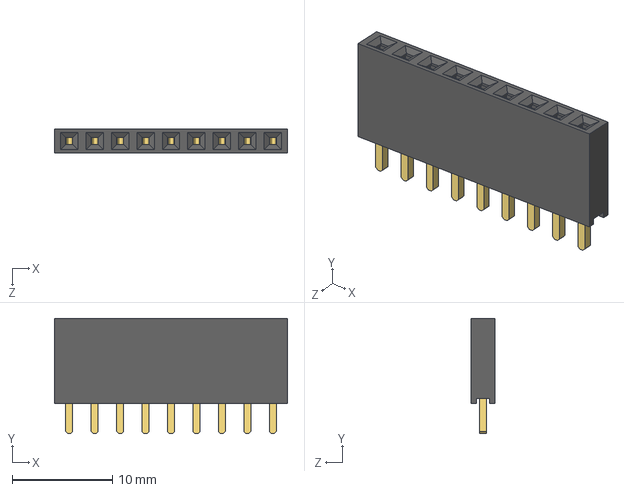
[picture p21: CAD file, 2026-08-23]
mechanical/cad/Circuit_Parts/pcb/New folder/100mill Female Pin Header_9P_Bk.STEP
23.3 x 11.5 x 2.40 mm

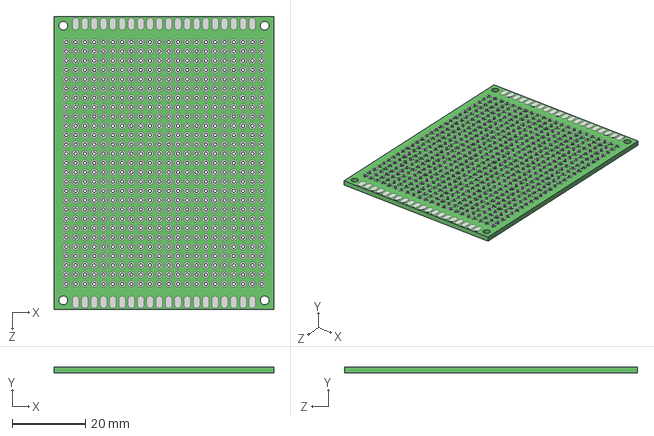
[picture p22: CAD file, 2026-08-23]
mechanical/cad/Circuit_Parts/pcb/PCB Prototype Development Board, 6x8 cm.STEP
60.0 x 1.70 x 80.0 mm

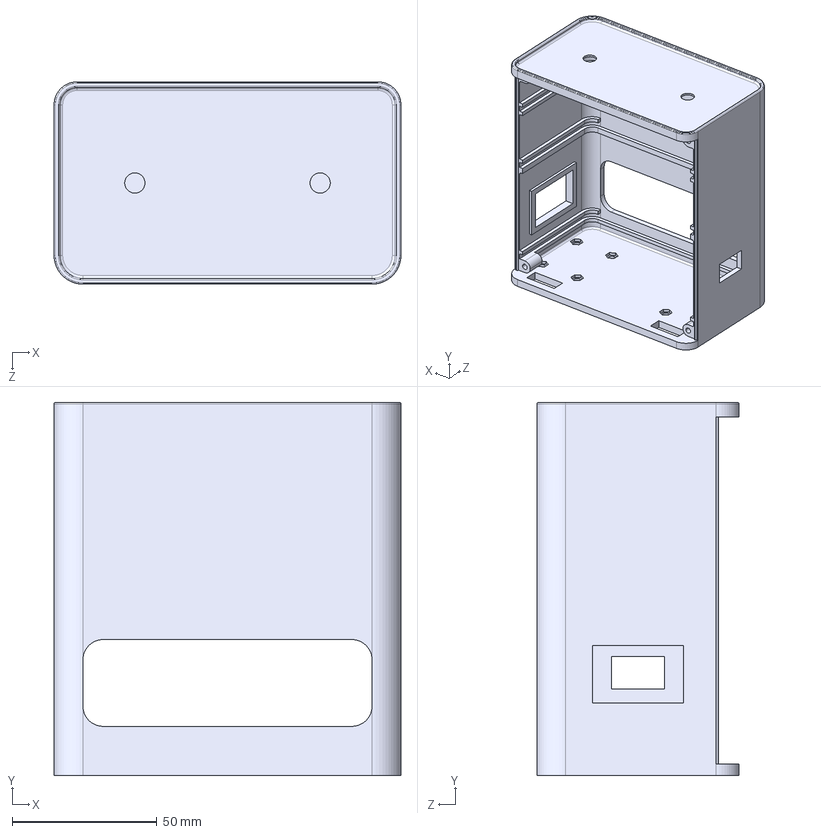
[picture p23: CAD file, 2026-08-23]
mechanical/cad/stl_print/Body_ver2.3.STEP
120.0 x 129.0 x 70.0 mm

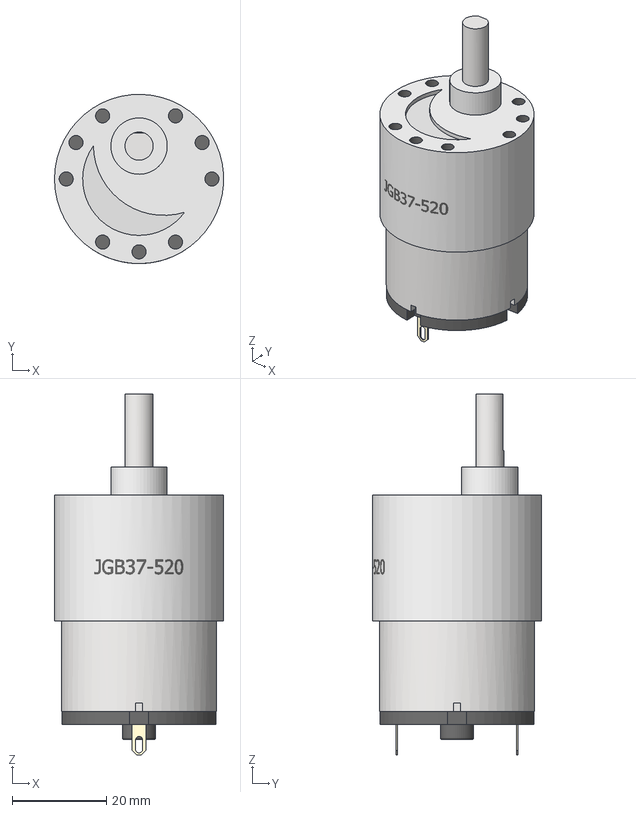
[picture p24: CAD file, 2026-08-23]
mechanical/cad/Circuit_Parts/dong co/JGB37-520.stp
36.0 x 36.0 x 76.8 mm

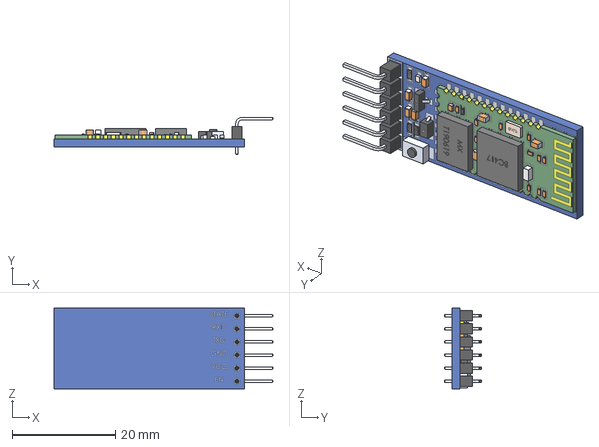
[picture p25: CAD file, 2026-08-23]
mechanical/cad/Circuit_Parts/hc05/HC05_pin.stp
42.5 x 7.25 x 15.7 mm

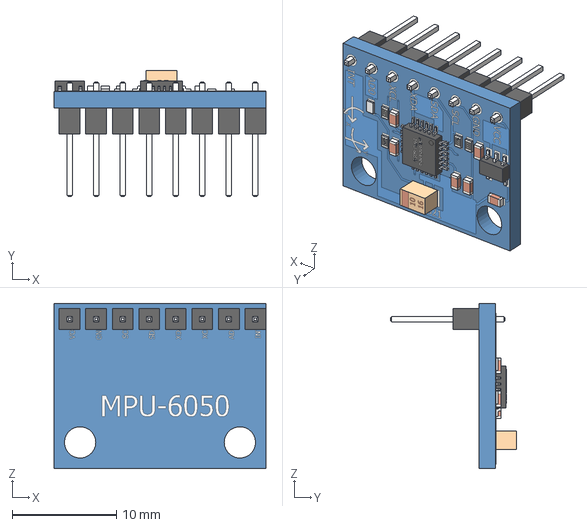
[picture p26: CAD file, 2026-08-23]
mechanical/cad/Circuit_Parts/mpu/MPU6050_pin.stp
20.3 x 12.1 x 15.8 mm

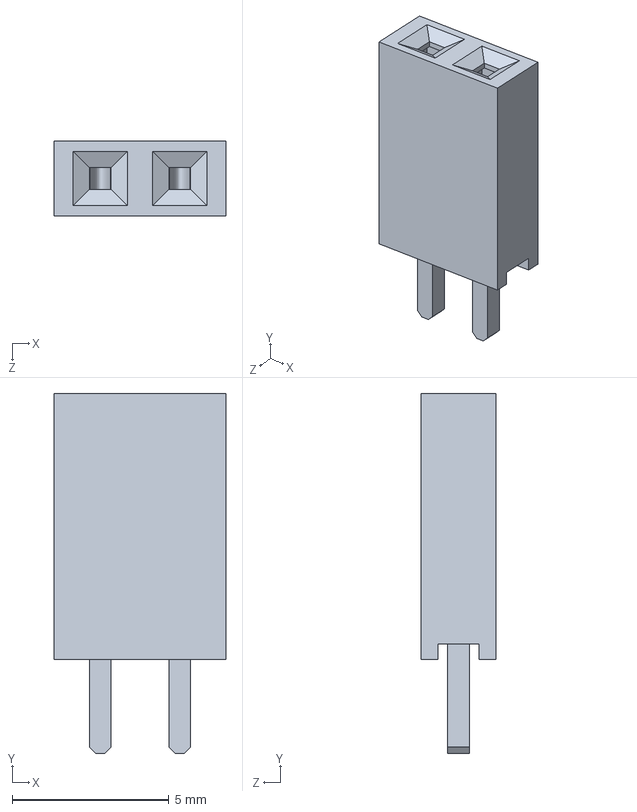
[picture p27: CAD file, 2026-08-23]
mechanical/cad/Circuit_Parts/pcb/100mil Female Pin Header.SLDPRT
5.48 x 11.5 x 2.40 mm

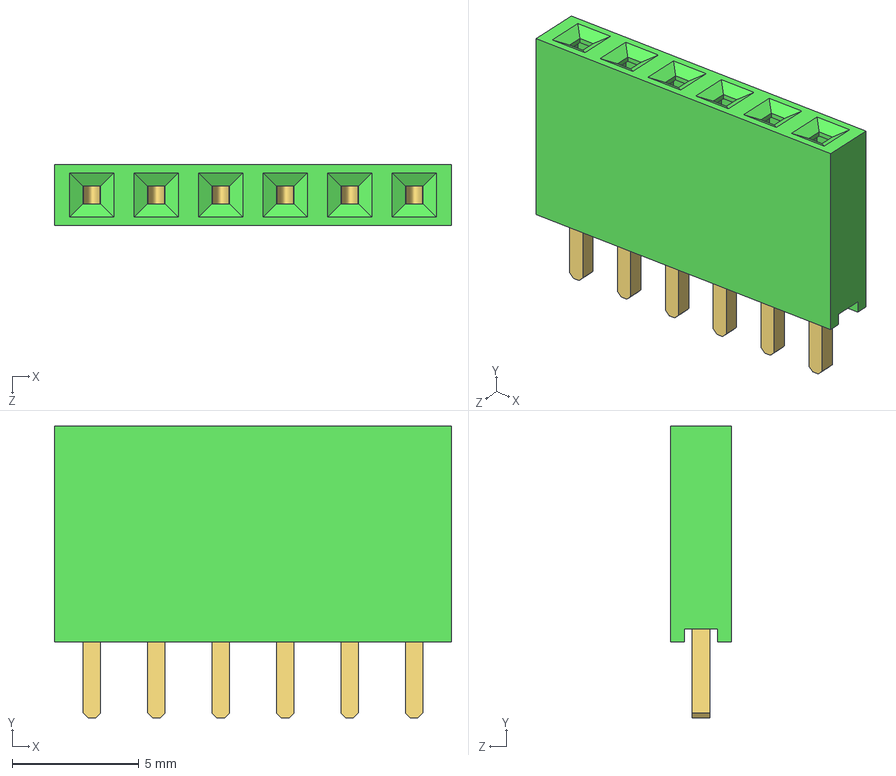
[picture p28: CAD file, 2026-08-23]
mechanical/cad/Circuit_Parts/pcb/New folder/100mill Female Pin Header_6P_Gr.STEP
15.6 x 11.5 x 2.40 mm

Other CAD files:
mechanical/cad/stl_print/Beam_ver2.STEP
mechanical/cad/Circuit_Parts/battery/3 Battery Holder.step
mechanical/cad/Circuit_Parts/dong co/TB6612FNG_pin.stp
mechanical/cad/Circuit_Parts/pcb/New folder/100mill Female Pin Header_3P_Gr.STEP
mechanical/cad/Circuit_Parts/battery/18650 Lipo Battery.step
mechanical/cad/Circuit_Parts/battery/4 Battery Holder With Batteries.step
mechanical/cad/Circuit_Parts/battery/4 Battery Holder.step
mechanical/cad/Circuit_Parts/battery/FreeCAD Files/18650 Lipo Battery.FCStd
mechanical/cad/Circuit_Parts/battery/FreeCAD Files/3 Battery Holder.FCStd
mechanical/cad/Circuit_Parts/battery/FreeCAD Files/4 Battery Holder.FCStd
mechanical/cad/Circuit_Parts/dong co/Motor mount.stp
mechanical/cad/Circuit_Parts/dong co/Wheel.stp
mechanical/cad/Circuit_Parts/pcb/New folder/100mil Female Pin Header_10P_Wi.STEP
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

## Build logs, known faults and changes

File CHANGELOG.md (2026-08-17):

# Changelog

All notable changes to the **Self-Balancing Robot** project will be documented in this file.

The format is based on [Keep a Changelog](https://keepachangelog.com/en/1.0.0/),
and this project adheres to [Semantic Versioning](https://semver.org/spec/v2.0.0.html).

## [0.1.0] - 2026-08-17

### Added
- Official repository initialized with Public access.
- Project overview and structure documented in `README.md`.
- Added open-source `LICENSE` (MIT) and `.gitignore` configuration.
- Setup directory tree for `firmware`, `hardware`, `mechanical`, `control`, `data`, `scripts`, `docs`, and `images`.

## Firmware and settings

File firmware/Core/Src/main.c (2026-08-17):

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
/* Includes ------------------------------------------------------------------*/
#include "main.h"

/* USER CODE BEGIN Includes */
#include <string.h>
#include <stdio.h>
#include <stdlib.h>
#include <math.h>

/* Bổ sung Module Debug */
#include "robot_debug.h"
/* USER CODE END Includes */

/* USER CODE BEGIN PTD */
typedef struct
{
    float Kp;
    float Ki;
    float Kd;
    
    float Ts;
    
    float setpoint;
    float feedback;
    float output;
    
    float error;
    float last_error;
    
    float integral;
    float derivative;

    float P_term;
    float I_term;
    float D_term;
    
    float outMax;
    float outMin;
    
    float iMax;
    float iMin;
    
    float *gyro;      // NULL nếu không dùng gyro
} PID_t;

typedef enum {
    MODE_MANUAL_PWM = 0,
    MODE_PID_SPEED  = 1
} ControlMode_t;

typedef enum {
    PRINT_OFF = 0,
    PRINT_MONITOR,   
    PRINT_PLOT,      
    PRINT_IMU,       
    PRINT_PLOTIMU    
} PrintMode_t;
/* USER CODE END PTD */

/* USER CODE BEGIN PD */
#define CONSTRAIN(x, lo, hi)  ((x) < (lo) ? (lo) : ((x) > (hi) ? (hi) : (x)))

/* ===== STATE-BASED RECOVERY CONTROLLER CONFIGURATION =====
 * Recovery là một thuật toán Linear State Feedback không dùng tích lũy:
 * RecoveryAngle = K_SPEED * Speed + K_ACCEL * Acceleration
 */
#define RECOVERY_SPEED_GAIN     0.015f   // Hệ số nhân cho Vận tốc (RPM)
#define RECOVERY_ACCEL_GAIN     0.0008f  // Hệ số nhân cho Gia tốc (RPM/s)
#define RECOVERY_ANGLE_GAIN     0.08f      // mới
#define RECOVERY_GYRO_GAIN      0.015f     // mới
#define ACC_FILTER_ALPHA        0.15f    // LPF coefficient cho gia tốc
#define MAX_RECOVERY_ANGLE      6.0f     // deg - giới hạn góc bù tối đa (default = 2)

#define SPEED_PID_ENABLE        0

#define SPEED_FILTER_ENABLE     1
#define SPEED_FILTER_ALPHA      0.12f

#define SPEED_DEADBAND_ENABLE   1
#define SPEED_DEADBAND_RPM      5.0f

#define SPEED_PID_PERIOD        5

#define SPEED_PID_KP            0.025f
#define SPEED_PID_KI            0.0010f
#define SPEED_PID_KD            0.0f

#define SPEED_PID_OUT_MAX       2.0f
#define SPEED_PID_OUT_MIN      -2.0f

#define SPEED_PID_IMAX          4.0f
#define SPEED_PID_IMIN         -4.0f

#define SPEED_PID_ENABLE_ANGLE  2.0f
#define ANGLE_OFFSET_SLEW       0.05f

#define ENCODER_CPR     1320.0f
#define SAMPLE_TIME     0.01f
#define RPM_FACTOR      (60.0f / (ENCODER_CPR * SAMPLE_TIME))
#define MPU6050_ADDR    (0x68 << 1)
#define DT              0.01f
#define M_PI            3.14159265358979323846
/* USER CODE END PD */

I2C_HandleTypeDef hi2c1;

TIM_HandleTypeDef htim2;
TIM_HandleTypeDef htim3;
TIM_HandleTypeDef htim4;

UART_HandleTypeDef huart1;

/* USER CODE BEGIN PV */
// Control & Mode Flags
volatile ControlMode_t control_mode = MODE_MANUAL_PWM; 
volatile PrintMode_t print_mode = PRINT_OFF;
volatile uint8_t print_flag = 0; 
uint8_t Enable_SpeedPID = SPEED_PID_ENABLE;

int manual_pwm = 0;
volatile int32_t encoder_position = 0;
volatile int16_t encoder_now = 0;
volatile int16_t encoder_old = 0;
volatile int16_t encoder_delta = 0;

// Các biến lưu tốc độ riêng biệt phục vụ Debug / Serial Plotter
volatile float encoder_rpm = 0.0f;
volatile float speed_raw = 0.0f;
volatile float speed_filtered = 0.0f;
volatile float speed_feedback = 0.0f;
volatile float speed_angle = 0.0f;      // Ngõ ra Speed PID (chính là Angle Offset)
volatile float target_speed = 0.0f;      // Sẵn sàng nhận lệnh tiến/lùi Bluetooth sau này

volatile uint32_t timer_cnt = 0;
volatile uint8_t pid_flag = 0;
volatile float pid_pwm;

// UART CLI Variables
volatile uint8_t rxChar;
char rxBuffer[32];
uint8_t rxIndex = 0;
volatile uint8_t cmdReady = 0;

PID_t Speed_PID;
PID_t Angle_PID;

// MPU Variables
HAL_StatusTypeDef mpuStatus;
uint8_t who_am_i;
uint8_t data;

uint8_t mpuData[16];

int16_t AccX, AccY, AccZ;
int16_t GyroX, GyroY, GyroZ;
int16_t Temp;

float Ax, Ay, Az;
float Gx, Gy, Gz;
float AccAngle = 0.0f;

float PitchAcc = 0.0f;
float Roll = 0.0f;
float RollAcc = 0.0f;
float RollGyro = 0.0f;
float GxOffset = 0.0f;

float Roll_Setpoint = 0.0f;
float BaseBalanceAngle = -0.25f;   // Góc cân bằng cơ khí (hằng số nền, không đổi bởi Recovery)
float BalanceAngle = 0.0f;         // = BaseBalanceAngle + RecoveryAngle, tính lại mỗi vòng lặp

float AngleOffset = 0.0f;

/* ===== STATE-BASED RECOVERY CONTROLLER VARIABLES ===== */
float LeftRPM = 0.0f;
float RightRPM = 0.0f;
float AverageRPM = 0.0f;

float Speed = 0.0f;
float LastSpeed = 0.0f;
float Acceleration = 0.0f;
float acc_filtered = 0.0f;

float RecoveryAngle = 0.0f;
int8_t RecoveryState = 0;
float AngleError = 0.0f;
float AngularVelocity = 0.0f;
/* USER CODE END PV */

void SystemClock_Config(void);
static void MX_GPIO_Init(void);
static void MX_TIM2_Init(void);
static void MX_TIM3_Init(void);
static void MX_TIM4_Init(void);
static void MX_USART1_UART_Init(void);
static void MX_I2C1_Init(void);
/* USER CODE BEGIN PFP */
void Error_Handler(void);
void HAL_TIM_MspPostInit(TIM_HandleTypeDef *htim);
void HAL_TIM_PeriodElapsedCallback(TIM_HandleTypeDef *htim);
void Motor_SetPWM(int left, int right);
void Motor_Left(int pwm);
void Motor_Right(int pwm);
void Encoder_Update(void);
void PID_Init(PID_t *pid);
float PID_Update(PID_t *pid);
void Process_Command(void);
void Process_Print(void);
void MPU6050_GyroCalibration(void);
void MPU6050_Read_Angle(void);
void Control_Loop(void);

// Modules độc lập cho Speed Control
void Speed_Filter(void);
void Speed_Deadband(void);
/* USER CODE END PFP */

/* USER CODE BEGIN 0 */

/* Module LPF Bậc 1 lọc nhiễu vận tốc */
void Speed_Filter(void)
{
#if SPEED_FILTER_ENABLE
    speed_filtered += SPEED_FILTER_ALPHA * (speed_raw - speed_filtered);
#else
    speed_filtered = speed_raw;
#endif
}

/* Module Deadband triệt tiêu rung lắc nhỏ khi đứng yên */
void Speed_Deadband(void)
{
#if SPEED_DEADBAND_ENABLE
    if (fabsf(speed_filtered) < SPEED_DEADBAND_RPM)
    {
        speed_feedback = 0.0f;
    }
    else
    {
        speed_feedback = speed_filtered;
    }
#else
    speed_feedback = speed_filtered;
#endif
}

/* USER CODE END 0 */

/**
  * @brief  The application entry point.
  * @retval int
  */
int main(void)
{

  /* MCU Configuration--------------------------------------------------------*/

  /* Reset of all peripherals, Initializes the Flash interface and the Systick. */
  HAL_Init();

  /* Configure the system clock */
  SystemClock_Config();

  /* Initialize all configured peripherals */
  MX_GPIO_Init();
  MX_TIM2_Init();
  MX_TIM3_Init();
  MX_TIM4_Init();
  MX_USART1_UART_Init();
  MX_I2C1_Init();
  /* USER CODE BEGIN 2 */
  // Khởi động PWM
  HAL_TIM_PWM_Start(&htim2, TIM_CHANNEL_1);
  HAL_TIM_PWM_Start(&htim2, TIM_CHANNEL_2);
  HAL_GPIO_WritePin(GPIOA, GPIO_PIN_4, GPIO_PIN_SET); // Kích hoạt TB6612

  // Khởi động Encoder TIM3
  HAL_TIM_Encoder_Start(&htim3, TIM_CHANNEL_ALL);
  encoder_old = (int16_t)__HAL_TIM_GET_COUNTER(&htim3);

  // ===== Cấu hình Speed PID =====
  Speed_PID.Kp = SPEED_PID_KP;
  Speed_PID.Ki = SPEED_PID_KI;
  Speed_PID.Kd = SPEED_PID_KD;
  Speed_PID.Ts = (float)SPEED_PID_PERIOD * SAMPLE_TIME; // 5 * 0.01s = 0.05s (50ms)

  Speed_PID.outMax = SPEED_PID_OUT_MAX;
  Speed_PID.outMin = SPEED_PID_OUT_MIN;
  Speed_PID.iMax   = SPEED_PID_IMAX;
  Speed_PID.iMin   = SPEED_PID_IMIN;

  PID_Init(&Speed_PID);
  Speed_PID.gyro = NULL;

  // ===== Cấu hình Angle PID =====
  Angle_PID.Kp = 520.0f;
  Angle_PID.Ki = 20.0f;
  Angle_PID.Kd = 12.0f;
  Angle_PID.Ts = DT;
  
  Angle_PID.outMax = 3590.0f; 
  Angle_PID.outMin = -3590.0f;
  Angle_PID.iMax   = 1300.0f;
  Angle_PID.iMin   = -1300.0f;
  
  PID_Init(&Angle_PID);
  Angle_PID.gyro = &Gx;

  // Wake up MPU6050
  data = 0x01; 
  HAL_I2C_Mem_Write(&hi2c1, MPU6050_ADDR, 0x6B, I2C_MEMADD_SIZE_8BIT, &data, 1, 100);
  HAL_Delay(200);

  // Calibrate Gyro
  MPU6050_GyroCalibration();

  // Đọc góc Roll ban đầu
  if(HAL_I2C_Mem_Read(&hi2c1, MPU6050_ADDR, 0x3B, I2C_MEMADD_SIZE_8BIT, mpuData, 6, 100) == HAL_OK)
  {
      AccX = (int16_t)(mpuData[0] << 8 | mpuData[1]);
      AccY = (int16_t)(mpuData[2] << 8 | mpuData[3]);
      AccZ = (int16_t)(mpuData[4] << 8 | mpuData[5]);
      
      float ax = (float)AccX / 16384.0f;
      float ay = (float)AccY / 16384.0f;
      float az = (float)AccZ / 16384.0f;
      
      Roll = atan2f(ay, sqrtf(ax * ax + az * az)) * 180.0f / M_PI;
  }

  // Khởi tạo Module Robot Debug
  RobotDebug_Init(&huart1);

  // Khởi động Ngắt Timer 10ms
  HAL_TIM_Base_Start_IT(&htim4);
  /* USER CODE END 2 */

  /* Infinite loop */
  /* USER CODE BEGIN WHILE */
  while (1)
  {
    /* USER CODE END WHILE */

    /* USER CODE BEGIN 3 */
  }
  /* USER CODE END 3 */
}

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
/* USER CODE BEGIN 4 */

void Motor_Left(int pwm)
{
    if(pwm > 3599) pwm = 3599;
    if(pwm < -3599) pwm = -3599;

    if(pwm >= 0)
    {
        HAL_GPIO_WritePin(GPIOA, GPIO_PIN_5, GPIO_PIN_SET);
        HAL_GPIO_WritePin(GPIOA, GPIO_PIN_6, GPIO_PIN_RESET);
        __HAL_TIM_SET_COMPARE(&htim2, TIM_CHANNEL_2, pwm);
    }
    else
    {
        HAL_GPIO_WritePin(GPIOA, GPIO_PIN_5, GPIO_PIN_RESET);
        HAL_GPIO_WritePin(GPIOA, GPIO_PIN_6, GPIO_PIN_SET);
        __HAL_TIM_SET_COMPARE(&htim2, TIM_CHANNEL_2, -pwm);
    }
}

void Motor_Right(int pwm)
{
    if(pwm > 3599) pwm = 3599;
    if(pwm < -3599) pwm = -3599;

    if(pwm >= 0)   
    {
        HAL_GPIO_WritePin(GPIOA, GPIO_PIN_2, GPIO_PIN_SET);
        HAL_GPIO_WritePin(GPIOA, GPIO_PIN_3, GPIO_PIN_RESET);
        __HAL_TIM_SET_COMPARE(&htim2, TIM_CHANNEL_1, pwm);
    }
    else
    {
        HAL_GPIO_WritePin(GPIOA, GPIO_PIN_2, GPIO_PIN_RESET);
        HAL_GPIO_WritePin(GPIOA, GPIO_PIN_3, GPIO_PIN_SET);
        __HAL_TIM_SET_COMPARE(&htim2, TIM_CHANNEL_1, -pwm);
    }
}

void Motor_SetPWM(int left, int right)
{
    Motor_Left(left);
    Motor_Right(right);
}

void Encoder_Update(void)
{
    encoder_now = (int16_t)__HAL_TIM_GET_COUNTER(&htim3);
    encoder_delta = encoder_now - encoder_old;
    encoder_old = encoder_now;

    encoder_position += encoder_delta;
    encoder_rpm = (float)encoder_delta * RPM_FACTOR;

    // Gán dữ liệu thô cho Speed Filter
    speed_raw = encoder_rpm;
}

void MPU6050_Read_Angle(void)
{
    if(HAL_I2C_Mem_Read(&hi2c1, MPU6050_ADDR, 0x3B, I2C_MEMADD_SIZE_8BIT, mpuData, 14, 2) == HAL_OK)
    {
        AccX  = (int16_t)(mpuData[0] << 8 | mpuData[1]);
        AccY  = (int16_t)(mpuData[2] << 8 | mpuData[3]);
        AccZ  = (int16_t)(mpuData[4] << 8 | mpuData[5]);
        GyroX = (int16_t)(mpuData[8] << 8 | mpuData[9]);

        Ax = (float)AccX / 16384.0f;
        Ay = (float)AccY / 16384.0f;
        Az = (float)AccZ / 16384.0f;
        
        Gx = ((float)GyroX / 131.0f) - GxOffset;

        RollAcc = atan2f(Ay, sqrtf(Ax * Ax + Az * Az)) * 180.0f / M_PI;
        Roll = 0.98f * (Roll + Gx * DT) + 0.02f * RollAcc;
    }
    else
    {
        HAL_I2C_DeInit(&hi2c1);
        HAL_I2C_Init(&hi2c1);
    }
}

void Control_Loop(void)
{
    static uint32_t last_tick = 0;
    uint32_t current_tick = HAL_GetTick(); 
    float loop_time_ms = (float)(current_tick - last_tick);
    if (last_tick == 0) loop_time_ms = 10.0f;
    last_tick = current_tick;

    static uint8_t speed_div = 0;

    //==================================================
    // 1. Đọc cảm biến
    //==================================================
    MPU6050_Read_Angle();
    Encoder_Update();

    Speed_Filter();
    Speed_Deadband();

    //==================================================
    // 2. Speed PID (50 ms)
    //==================================================
    if (Enable_SpeedPID)
    {
        if (++speed_div >= SPEED_PID_PERIOD)
        {
            speed_div = 0;

            if (fabsf(Roll - BalanceAngle) < SPEED_PID_ENABLE_ANGLE)
            {
                Speed_PID.setpoint = target_speed;
                Speed_PID.feedback = speed_feedback;

                speed_angle = PID_Update(&Speed_PID);
            }
            else
            {
                speed_angle = 0.0f;
                Speed_PID.integral = 0.0f;
                Speed_PID.last_error = 0.0f;
            }
        }
    }
    else
    {
        speed_angle = 0.0f;
        Speed_PID.integral = 0.0f;
        Speed_PID.last_error = 0.0f;
    }

    //==================================================
    // 3. Slew Rate Limit cho AngleOffset
    //==================================================
    {
        float delta = speed_angle - AngleOffset;

        if (delta > ANGLE_OFFSET_SLEW)
            delta = ANGLE_OFFSET_SLEW;
        else if (delta < -ANGLE_OFFSET_SLEW)
            delta = -ANGLE_OFFSET_SLEW;

        AngleOffset += delta;
    }

    //==================================================
    // 3.5. STATE-BASED RECOVERY CONTROLLER
    //      Linear State Feedback: RecoveryAngle = K_SPEED * Speed + K_ACCEL * Acceleration
    //==================================================
    LeftRPM = encoder_rpm;
    RightRPM = encoder_rpm;
    AverageRPM = (LeftRPM + RightRPM) * 0.5f;

    // Trạng thái vận tốc hiện tại
    Speed = encoder_rpm;

    // Tính gia tốc thô (RPM/s)
    Acceleration = (Speed - LastSpeed) / DT;
    LastSpeed = Speed;

    // Lọc gia tốc bằng Low-Pass Filter để triệt tiêu nhiễu từ encoder
    acc_filtered += ACC_FILTER_ALPHA * (Acceleration - acc_filtered);

	AngularVelocity = Gx;
	// Tính trực tiếp RecoveryAngle theo trạng thái hiện tại (không tích lũy)
    RecoveryAngle =
      RECOVERY_SPEED_GAIN * Speed
    + RECOVERY_ACCEL_GAIN * acc_filtered
    + RECOVERY_GYRO_GAIN * AngularVelocity;
	
    // Giới hạn biên độ RecoveryAngle
    RecoveryAngle = CONSTRAIN(RecoveryAngle, -MAX_RECOVERY_ANGLE, MAX_RECOVERY_ANGLE);

    // Cập nhật trạng thái cho RobotDebug
    if (RecoveryAngle > 0.05f)
        RecoveryState = 1;
    else if (RecoveryAngle < -0.05f)
        RecoveryState = -1;
    else
        RecoveryState = 0;

    // Cập nhật góc cân bằng mục tiêu cho Angle PID
    BalanceAngle = BaseBalanceAngle + RecoveryAngle;

    //==================================================
    // 4. Angle PID (10 ms)
    //==================================================
    Angle_PID.setpoint = BalanceAngle + AngleOffset;
    Angle_PID.feedback = Roll;

    pid_pwm = PID_Update(&Angle_PID);

    //==================================================
    // 5. Safety & Output
    //==================================================
    if (fabsf(Roll) > 45.0f)
    {
        Motor_SetPWM(0, 0);

        PID_Init(&Angle_PID);
        PID_Init(&Speed_PID);

        AngleOffset = 0.0f;
        speed_angle = 0.0f;
        speed_filtered = 0.0f;
        speed_feedback = 0.0f;

        // Reset trạng thái Recovery khi xe đổ
        RecoveryAngle = 0.0f;
        Speed = 0.0f;
        LastSpeed = 0.0f;
        Acceleration = 0.0f;
        acc_filtered = 0.0f;
        RecoveryState = 0;
    }
    else
    {
        Motor_SetPWM((int)pid_pwm, (int)pid_pwm);
    }

    //==================================================
    // 6. DEBUG MODULE UPDATE
    //==================================================
    RobotDebug_Update(
        HAL_GetTick(),             // Thời gian (ms)
        Roll,                      // Góc Roll
        Gx,                        // Gx đã được trừ offset
        LeftRPM,                   // LeftRPM
        RightRPM,                  // RightRPM
        pid_pwm,                   // PWM thực tế bánh trái
        pid_pwm,                   // PWM thực tế bánh phải
        Angle_PID.setpoint,        // Setpoint góc (BalanceAngle + AngleOffset)
        Angle_PID.feedback,        // Pitch/Roll feedback
        Angle_PID.error,           // Sai số góc
        Angle_PID.P_term,          // Tỉ lệ P
        Angle_PID.I_term,          // Tích phân I
        Angle_PID.D_term,          // Vi phân D
        Angle_PID.output,          // PID_Output
        AngleOffset,               // Biến AngleOffset từ Speed PID
        loop_time_ms,              // Thời gian thi hành vòng lặp (ms)
        AverageRPM,                // AverageRPM
        Acceleration,              // Gia tốc (thay thế cho DeltaSpeed cũ)
        RecoveryAngle,             // RecoveryAngle
        RecoveryState,             // Flag recovery mode
        BaseBalanceAngle,          // BaseBalanceAngle
        BalanceAngle               // BalanceAngle
    );
}

void HAL_TIM_PeriodElapsedCallback(TIM_HandleTypeDef *htim)
{
    if(htim->Instance == TIM4)
    {
        timer_cnt++; 
        pid_flag = 1;
    }
}

void PID_Init(PID_t *pid)
{
    pid->error = 0.0f;
    pid->last_error = 0.0f;
    pid->integral = 0.0f;
    pid->derivative = 0.0f;
    pid->P_term = 0.0f;
    pid->I_term = 0.0f;
    pid->D_term = 0.0f;
    pid->output = 0.0f;
    pid->setpoint = 0.0f;
    pid->feedback = 0.0f;
}

float PID_Update(PID_t *pid)
{
    pid->error = pid->setpoint - pid->feedback;
    
    // Tích phân
    pid->integral += pid->error * pid->Ts;
    if(pid->integral > pid->iMax) pid->integral = pid->iMax;
    if(pid->integral < pid->iMin) pid->integral = pid->iMin;

    // Vi phân
    if (pid->gyro != NULL)
    {
        // Angle PID dùng trực tiếp Gyro
        pid->derivative = -(*pid->gyro);
    }
    else
    {
        // Speed PID giữ nguyên
        pid->derivative = (pid->error - pid->last_error) / pid->Ts;
    }

    // Thành phần P, I, D
    pid->P_term = pid->Kp * pid->error;
    pid->I_term = pid->Ki * pid->integral;
    pid->D_term = pid->Kd * pid->derivative;

    // Ngõ ra
    pid->output = pid->P_term + pid->I_term + pid->D_term;

    if(pid->output > pid->outMax) pid->output = pid->outMax;
    if(pid->output < pid->outMin) pid->output = pid->outMin;

    pid->last_error = pid->error;

    return pid->output;
}

void Process_Print(void) {}
void Process_Command(void) {}
void HAL_UART_RxCpltCallback(UART_HandleTypeDef *huart) {}
void HAL_UART_ErrorCallback(UART_HandleTypeDef *huart) {}

void MPU6050_GyroCalibration(void)
{
    float sum = 0.0f;
    for(int i = 0; i < 500; i++)
    {
        if(HAL_I2C_Mem_Read(&hi2c1, MPU6050_ADDR, 0x43, I2C_MEMADD_SIZE_8BIT, &mpuData[8], 2, 10) == HAL_OK)
        {
            int16_t raw_gx = (int16_t)(mpuData[8] << 8 | mpuData[9]);
            sum += ((float)raw_gx / 131.0f);
        }
        HAL_Delay(2);
    }
    GxOffset = sum / 500.0f;
}

/* USER CODE END 4 */
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


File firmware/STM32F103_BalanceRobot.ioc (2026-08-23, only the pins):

Mcu.UserName=STM32F103C8Tx
PA0-WKUP.Signal=S_TIM2_CH1_ETR
PA1.Signal=S_TIM2_CH2
PA10.Signal=USART1_RX
PA13.Signal=SYS_JTMS-SWDIO
PA14.Signal=SYS_JTCK-SWCLK
PA2.Signal=GPIO_Output
PA3.Signal=GPIO_Output
PA4.Signal=GPIO_Output
PA5.Signal=GPIO_Output
PA6.Signal=GPIO_Output
PA9.Signal=USART1_TX
PB4.Signal=S_TIM3_CH1
PB5.Signal=S_TIM3_CH2
PB6.Signal=I2C1_SCL
PB7.Signal=I2C1_SDA
PD0-OSC_IN.Signal=RCC_OSC_IN
PD1-OSC_OUT.Signal=RCC_OSC_OUT

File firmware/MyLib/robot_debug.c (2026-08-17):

/**
  ******************************************************************************
  * @file    robot_debug.c
  * @brief   Implementation file for Robot Debug Module
  ******************************************************************************
  */

#include "robot_debug.h"

/* Private Variables ---------------------------------------------------------*/
static UART_HandleTypeDef *debug_huart = NULL;
static RobotDebug_Data_t debug_data;
static RingBuffer_t tx_ring_buf = { .head = 0, .tail = 0 };
static volatile uint8_t uart_tx_busy = 0;

/* Private Function Prototypes -----------------------------------------------*/
static void RingBuffer_Write(const char *data, uint16_t len);
static uint16_t RingBuffer_Read(char *data, uint16_t max_len);

/* Public Functions ----------------------------------------------------------*/

/**
  * @brief Khoi tao module debug voi UART truyen vao
  */
void RobotDebug_Init(UART_HandleTypeDef *huart)
{
    debug_huart = huart;
    tx_ring_buf.head = 0;
    tx_ring_buf.tail = 0;
    uart_tx_busy = 0;
    memset((void*)&debug_data, 0, sizeof(RobotDebug_Data_t));
}

/**
  * @brief Cap nhat tat ca cac thong so telemetry cua Robot
  */
void RobotDebug_Update(
    uint32_t tick,
    float roll,
    float gx,
    float rpm_l,
    float rpm_r,
    float pwm_l,
    float pwm_r,
    float setpoint,
    float feedback,
    float error,
    float p_term,
    float i_term,
    float d_term,
    float output,
    float angle_offset,
    float loop_time,
    float average_rpm,
    float delta_speed,
    float recovery_angle,
    int8_t recovery_state,
    float base_balance_angle,
    float balance_angle
)
{
    debug_data.timestamp       = tick;
    debug_data.roll            = roll;
    debug_data.gyro_x          = gx;
    debug_data.rpm_l           = rpm_l;
    debug_data.rpm_r           = rpm_r;
    debug_data.pwm_l           = pwm_l;
    debug_data.pwm_r           = pwm_r;
    debug_data.angle_setpoint  = setpoint;
    debug_data.angle_feedback  = feedback;
    debug_data.angle_error     = error;
    debug_data.p_term          = p_term;
    debug_data.i_term          = i_term;
    debug_data.d_term          = d_term;
    debug_data.angle_output    = output;
    debug_data.angle_offset    = angle_offset;
    debug_data.loop_time_ms    = loop_time;
    debug_data.average_rpm      = average_rpm;
    debug_data.delta_speed      = delta_speed;
    debug_data.recovery_angle   = recovery_angle;
	debug_data.recovery_state = recovery_state;
    debug_data.base_balance_angle = base_balance_angle;
    debug_data.balance_angle    = balance_angle;

    // Dong goi chuoi dinh dang Serial Plotter / CSV Debug (phan tach boi dau phay)
    // Thu tu: Roll,GyroX,Setpoint,P,I,D,PID_Output,AngleOffset,LoopTime,
    //         LeftRPM,RightRPM,AverageRPM,DeltaSpeed,RecoveryAngle,BaseBalanceAngle,BalanceAngle
    char msg_buf[256];
    int len = snprintf(msg_buf, sizeof(msg_buf),
        "%.2f,%.2f,%.2f,%.2f,%.2f,%.2f,%.2f,%.2f,%.2f,"
		"%.2f,%.2f,%.2f,%.2f,%.3f,%d,%.2f,%.2f\r\n",
        debug_data.roll,
        debug_data.gyro_x,
        debug_data.angle_setpoint,
        debug_data.p_term,
        debug_data.i_term,
        debug_data.d_term,
        debug_data.angle_output,       // PID_Output
        debug_data.angle_offset,
        debug_data.loop_time_ms,
        debug_data.rpm_l,              // LeftRPM
        debug_data.rpm_r,              // RightRPM
        debug_data.average_rpm,        // AverageRPM
        debug_data.delta_speed,        // DeltaSpeed
        debug_data.recovery_angle,     // RecoveryAngle
		debug_data.recovery_state,     // Flag
        debug_data.base_balance_angle, // BaseBalanceAngle
        debug_data.balance_angle       // BalanceAngle
    );

    if (len > 0)
    {
        RingBuffer_Write(msg_buf, (uint16_t)len);
    }
}

/**
  * @brief Xu ly day du lieu tu Ring Buffer ra cong UART (goi trong while(1))
  */
void RobotDebug_ProcessUART(void)
{
    if (debug_huart == NULL) return;

    // Neu UART chua ban va bo dem co du lieu -> day ra UART DMA/IT hoac Polling
    if (!uart_tx_busy && (tx_ring_buf.head != tx_ring_buf.tail))
    {
        static char temp_tx[128];
        uint16_t len = RingBuffer_Read(temp_tx, sizeof(temp_tx));

        if (len > 0)
        {
            // Dung Blocking Mode an toan chong ghi de khi truyen du lieu toc do cao
            HAL_UART_Transmit(debug_huart, (uint8_t*)temp_tx, len, 10);
        }
    }
}

/* Private Functions ---------------------------------------------------------*/

static void RingBuffer_Write(const char *data, uint16_t len)
{
    for (uint16_t i = 0; i < len; i++)
    {
        uint16_t next_head = (tx_ring_buf.head + 1) % DEBUG_RING_BUF_SIZE;
        if (next_head != tx_ring_buf.tail) // Neu chua day bo dem
        {
            tx_ring_buf.buffer[tx_ring_buf.head] = data[i];
            tx_ring_buf.head = next_head;
        }
        else
        {
            break; // Tran bo dem, bo qua cac ky tu con lai
        }
    }
}

static uint16_t RingBuffer_Read(char *data, uint16_t max_len)
{
    uint16_t count = 0;
    while ((tx_ring_buf.head != tx_ring_buf.tail) && (count < max_len))
    {
        data[count++] = tx_ring_buf.buffer[tx_ring_buf.tail];
        tx_ring_buf.tail = (tx_ring_buf.tail + 1) % DEBUG_RING_BUF_SIZE;
    }
    return count;
}

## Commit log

2026-08-17 feat(firmware): add STM32 CubeMX, Keil C project, and custom drivers
2026-08-23 feat(hardware): add schematics, PCB layout, wiring, and BOM
2026-08-23 Feat: Add mechanical STL files, drawings, and printing instructions
    [Beam_ver2.STEP, Body_ver2.3.3mf, Body_ver2.3.STEP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]
2026-08-23 Feat: Add 3D assembly STEP file
2026-08-23 docs: update README repository tree with docs and circuit_parts
2026-08-23 feat: upload full docs folder (datasheets, handbook, pinout) and circuit_parts CAD models
    [100mil Female Pin Header.SLDPRT, 100mil Female Pin Header_10P_Wi.STEP, 100mil Female Pin Header_12P_Wi.STEP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]
